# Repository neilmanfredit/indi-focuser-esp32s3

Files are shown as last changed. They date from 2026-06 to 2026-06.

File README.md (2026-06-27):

# indi-focuser-esp32s3


[]()
[]()
[]()
[]()

**A low-cost, open-source motorised telescope focuser for Linux, PHD2, and KStars/Ekos.**

Built around a **28BYJ-48 stepper motor**, **ULN2003 driver board**, and an **Arduino Nano ESP32 (ESP32-S3R8)**. Controlled over USB from any Linux machine via a native INDI driver. No Windows required. No ASCOM required.

3D-printable motor mounts in PETG are included for three telescopes:

| Telescope | Focuser type |
|---|---|
| RVO Horizon 60 ED | Dual-speed rack-and-pinion |
| Celestron NexStar 8SE | SCT mirror-shift |
| SkyWatcher Explorer 200P | 2" Crayford Newtonian |

---

## Why this project exists

Commercial motorised focusers start at £150 and climb quickly. The hardware in this project costs under £15. Most DIY focuser projects target Windows with ASCOM. This one is built for Linux from the ground up — it runs directly on a Raspberry Pi, a mini PC, or any Debian/Arch machine driving your imaging rig.

This project was inspired by the hardware design of [jlecomte/ascom-oag-focuser](https://github.com/jlecomte/ascom-oag-focuser) — an excellent Windows/ASCOM project. The firmware, INDI driver, and 3D files here are independent, original work. See [NOTICE](NOTICE) for full attribution.

---

## What you need to build this

### Electronics (under £15 total)

| Part | Approx cost |
|---|---|
| Arduino Nano ESP32 (ESP32-S3R8) | £8–12 |
| 28BYJ-48 stepper + ULN2003 board (sold as a kit) | £2–3 |
| USB-C cable | Already have one |

### 3D printing

- Any FDM printer
- PETG filament (mandatory for outdoor use — see [docs/3d_printing.md](docs/3d_printing.md))
- ~50g filament per mount

### Tools

- Soldering iron (for heat-set inserts)
- M3 and M2 heat-set inserts
- M3 and M2 socket cap screws (see each SCAD file for exact quantities)
- Calipers (to verify your focuser dimensions before printing)

---

## Repository layout

```
indi-focuser-esp32s3/
│
├── firmware/
│   └── oag_focuser_firmware.ino     Arduino firmware (ESP32-S3)
│
├── indi_driver/
│   ├── indi_oag_focuser.h           INDI driver header
│   ├── indi_oag_focuser.cpp         INDI driver implementation
│   ├── indi_oag_focuser.xml         INDI device descriptor
│   └── CMakeLists.txt               Build system
│
├── 3d_files/
│   ├── rvo-horizon-60ed/
│   │   └── rvo_horizon_60ed_motor_mount.scad
│   ├── celestron-nexstar-8se/
│   │   └── nexstar_8se_motor_mount.scad
│   └── skywatcher-explorer-200p/
│       └── sw_explorer_200p_motor_mount.scad
│
├── scripts/
│   ├── oag_focuser_test.py          Serial test and calibration utility
│   └── 99-oag-focuser.rules         udev stable device symlink
│
├── docs/
│   ├── wiring.md                    Wiring guide
│   ├── build.md                     INDI driver build instructions
│   ├── calibration.md               Focuser calibration procedure
│   └── 3d_printing.md               Print settings and assembly
│
├── LICENSE                          MIT
├── NOTICE                           Third-party attribution
├── CONTRIBUTING.md
└── README.md
```

---

## Wiring

```
Arduino Nano ESP32 (3.3V logic)      ULN2003 board         28BYJ-48 motor
────────────────────────────────     ─────────────          ──────────────
D2  ────────────────────────────►  IN1
D3  ────────────────────────────►  IN2
D4  ────────────────────────────►  IN3
D5  ────────────────────────────►  IN4
5V  ────────────────────────────►  VCC  ◄────────────────── motor +5V
GND ────────────────────────────►  GND
                                    OUT1-4 ─────────────►  motor coils
```

**Key points for the ESP32-S3:**
- The motor runs on **5V** — connect ULN2003 VCC to the board's 5V pin (VBUS), not 3.3V
- The 3.3V GPIO signals are sufficient to trigger the ULN2003 inputs (threshold ~1V)
- Use the **D-label pin names** (D2, D3, D4, D5) in code — bare integers map to raw GPIO numbers on ESP32, which are different from the silkscreen labels
- The board enumerates as `/dev/ttyACM0` on Linux — no CH340 driver needed

See [docs/wiring.md](docs/wiring.md) for the full pinout table and connector details.

---

## Quick start

### Step 1 — Flash the firmware

1. Install the [Arduino IDE](https://www.arduino.cc/en/software)
2. Add the ESP32 board package: **Boards Manager** → search `esp32` → install **Arduino ESP32 Boards** by Arduino
3. Select: **Tools → Board → Arduino ESP32 Boards → Arduino Nano ESP32**
4. Open `firmware/oag_focuser_firmware.ino`
5. Connect via USB-C and click **Upload**

> If the upload fails, double-tap the reset button to enter bootloader mode — the RGB LED will pulse green.

### Step 2 — Test the hardware (no INDI needed)

```bash
pip install pyserial
python3 scripts/oag_focuser_test.py --port /dev/ttyACM0 --test
```

Or interactive mode for manual calibration:

```bash
python3 scripts/oag_focuser_test.py --port /dev/ttyACM0 -i
```

Available commands in interactive mode:

| Command | Action |
|---|---|
| `pos` | Report current position |
| `move <n>` | Move to absolute position n |
| `halt` | Stop immediately |
| `zero` | Set current position as zero |
| `rev on/off` | Reverse motor direction |
| `test` | Run automated self-test |

### Step 3 — Install the udev rule

Gives the device a stable name (`/dev/focuser`) regardless of which USB port you use:

```bash
sudo cp scripts/99-oag-focuser.rules /etc/udev/rules.d/
sudo udevadm control --reload-rules
sudo udevadm trigger
ls -la /dev/focuser   # should appear
```

### Step 4 — Build and install the INDI driver

```bash
# Debian / Ubuntu / Raspberry Pi OS
sudo apt install libindi-dev libnova-dev cmake build-essential

# Arch Linux / Garuda Linux
sudo pacman -S indi libnova cmake base-devel

cd indi_driver
mkdir build && cd build
cmake ..
make -j$(nproc)
sudo make install
```

### Step 5 — Run

```bash
indiserver -v indi_oag_focuser
```

Connect **KStars/Ekos** or **PHD2** to `localhost:7624` and select **OAG Focuser**. Set the serial port to `/dev/ttyACM0` (or `/dev/focuser` if the udev rule is installed).

---

## Serial protocol

The firmware speaks a simple newline-terminated text protocol over USB serial at 115200 baud. Compatible with the protocol used by jlecomte/ascom-oag-focuser, so any tooling built for that project will also work here.

| Command | Response |
|---|---|
| `COMMAND:FOCUSER:HANDSHAKE` | `REPLY:FOCUSER:READY` |
| `COMMAND:FOCUSER:GETPOSITION` | `REPLY:FOCUSER:POSITION:<n>` |
| `COMMAND:FOCUSER:ISMOVING` | `REPLY:FOCUSER:ISMOVING:<0\|1>` |
| `COMMAND:FOCUSER:GETMAXPOSITION` | `REPLY:FOCUSER:MAXPOSITION:32767` |
| `COMMAND:FOCUSER:MOVE:<n>` | `REPLY:FOCUSER:OK` |
| `COMMAND:FOCUSER:HALT` | `REPLY:FOCUSER:OK` |
| `COMMAND:FOCUSER:SETZERO` | `REPLY:FOCUSER:OK` |
| `COMMAND:FOCUSER:GETREVERSE` | `REPLY:FOCUSER:REVERSE:<0\|1>` |
| `COMMAND:FOCUSER:SETREVERSE:<0\|1>` | `REPLY:FOCUSER:OK` |

Position is stored to flash on every stop and survives power cycles.

---

## 3D files

All mounts are **OpenSCAD parametric models**. Open in [OpenSCAD](https://openscad.org/) (free), adjust the parameters at the top to match your focuser, press **F6** to render, then **File → Export → Export as STL**.

**Measure your focuser with calipers before printing.** The key dimension to check per telescope:

| Telescope | File | Key parameter | Default |
|---|---|---|---|
| RVO Horizon 60 ED | `rvo_horizon_60ed_motor_mount.scad` | `focuser_body_w` | 58 mm |
| Celestron NexStar 8SE | `nexstar_8se_motor_mount.scad` | `focus_shaft_od` | 13.1 mm |
| SkyWatcher Explorer 200P | `sw_explorer_200p_motor_mount.scad` | `focuser_body_w` | 76 mm |

Each SCAD file produces all parts needed for that telescope: motor bracket/plate, drive gear, motor pinion, electronics box, and lid.

Print in **PETG**. See [docs/3d_printing.md](docs/3d_printing.md) for full print settings, Bambu Labs H2S notes, and assembly guidance.

---

## Calibration

See [docs/calibration.md](docs/calibration.md) for the full procedure. In summary:

1. Set zero at the mechanical end stop
2. Confirm motor direction (reverse if needed)
3. Measure backlash with a dial indicator
4. Test from INDI

---

## ESP32-S3 firmware notes

Several things behave differently on ESP32-S3 compared to an ATmega Nano. The firmware handles all of these but they are worth understanding:

| Issue | ATmega Nano | ESP32-S3 | Solution in firmware |
|---|---|---|---|
| EEPROM | Built-in hardware | Flash emulation | `EEPROM.begin()` + `EEPROM.commit()` |
| Pin defaults | Defined at startup | Float — no default state | Explicit `pinMode(x, OUTPUT)` for all motor pins |
| Pin numbering | Integer = physical label | Integer = raw GPIO number | D-label names used throughout |
| USB device | `/dev/ttyUSB0` (CH340) | `/dev/ttyACM0` (native CDC) | udev rule provided |
| Logic voltage | 5V | 3.3V | ULN2003 inputs work fine at 3.3V |

---

## Troubleshooting

| Symptom | Likely cause | Fix |
|---|---|-----|
| Motor hums but doesn't turn | ULN2003 VCC on 3.3V pin | Move VCC wire to 5V pin |
| Motor turns wrong way | Wiring or direction flag | `rev on` in test utility |
| `/dev/ttyACM0` missing | Board not in run mode | Double-tap reset; try different cable |
| Handshake fails | Wrong port | `ls /dev/ttyACM*`; check firmware flashed |
| INDI driver not found | XML not installed | Verify `/usr/share/indi/indi_oag_focuser.xml` |
| Position lost on restart | EEPROM not committing | Reflash firmware; do not modify EEPROM calls |
| Gear slips under load | Underpowered 28BYJ-48 | Increase `STEP_DELAY_US` to 1500 in firmware |

---

## Contributing

Pull requests are welcome. Adding a mount design for a new telescope is particularly useful — see [CONTRIBUTING.md](CONTRIBUTING.md).

---

## Licence

MIT — see [LICENSE](LICENSE) — CC BY-NC-SA 4.0, non-commercial use only.

This project is independent and not affiliated with Julien Lecomte's ascom-oag-focuser. See [NOTICE](NOTICE) for attribution.

---

## Acknowledgements

Hardware concept and serial protocol inspired by [jlecomte/ascom-oag-focuser](https://github.com/jlecomte/ascom-oag-focuser) by Julien Lecomte (DarkSkyGeek). Original work in all firmware, driver, and 3D files.

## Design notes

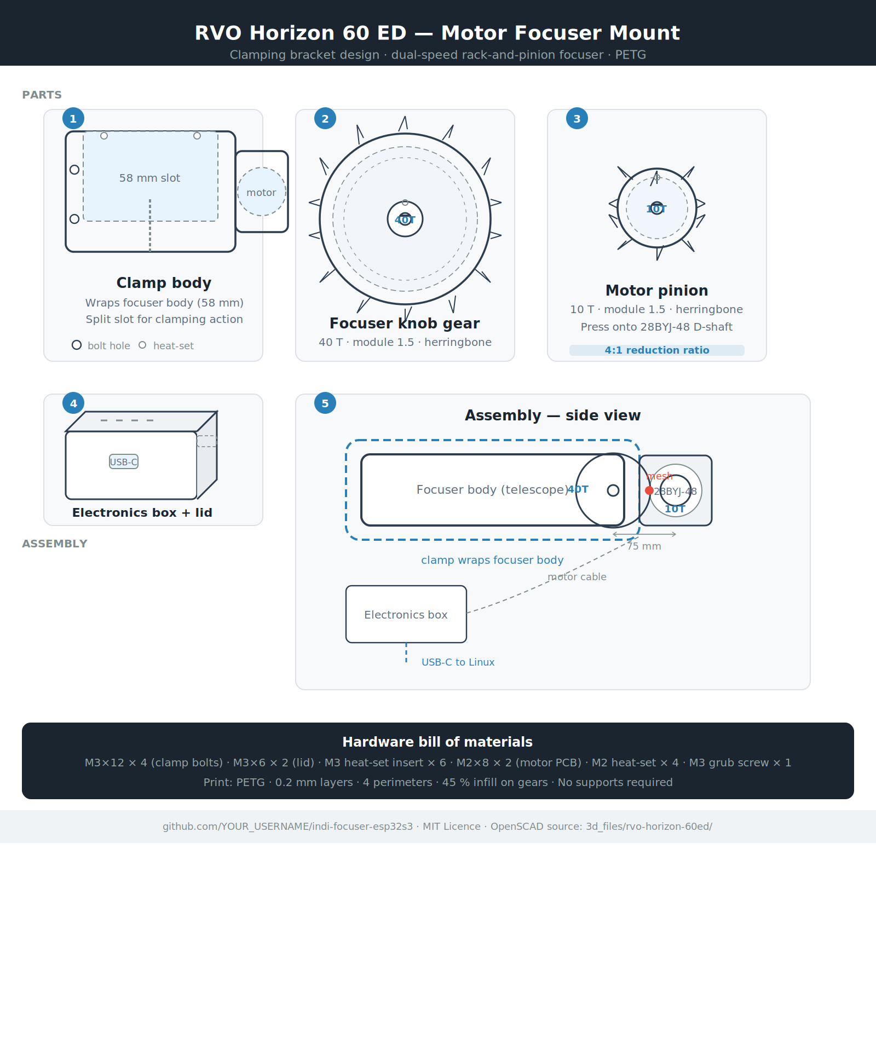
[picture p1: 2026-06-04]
docs/images/rvo_horizon_60ed_mount.png

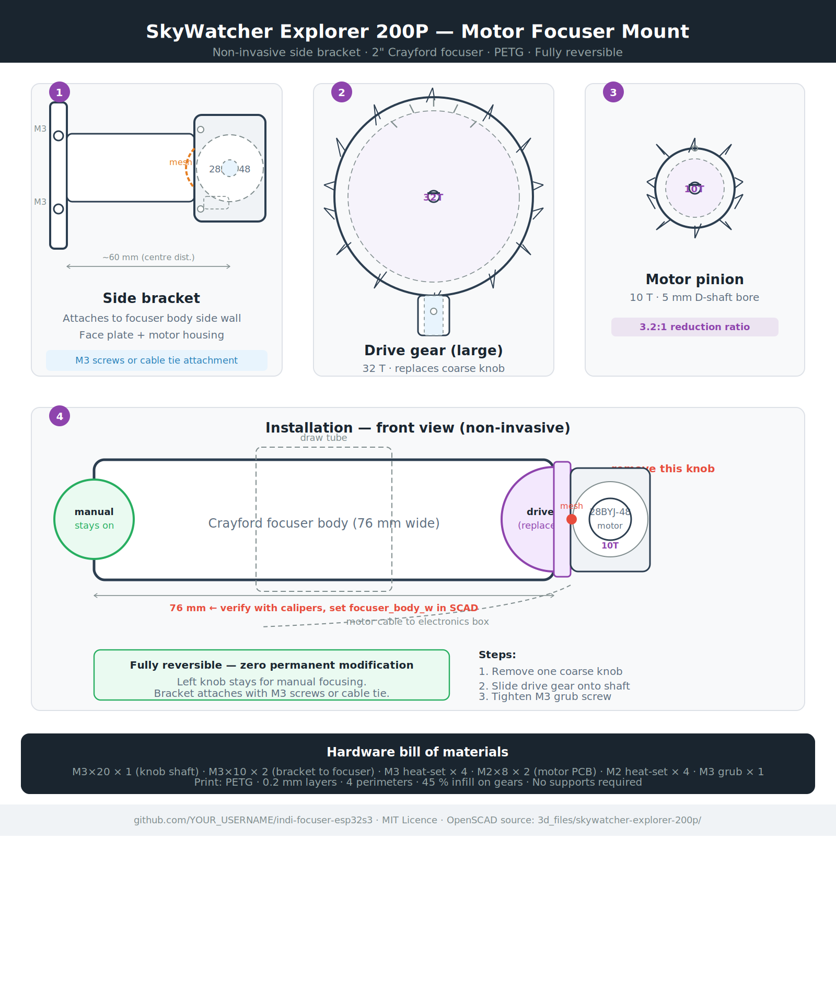
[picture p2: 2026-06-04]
docs/images/sw_explorer_200p_mount.png

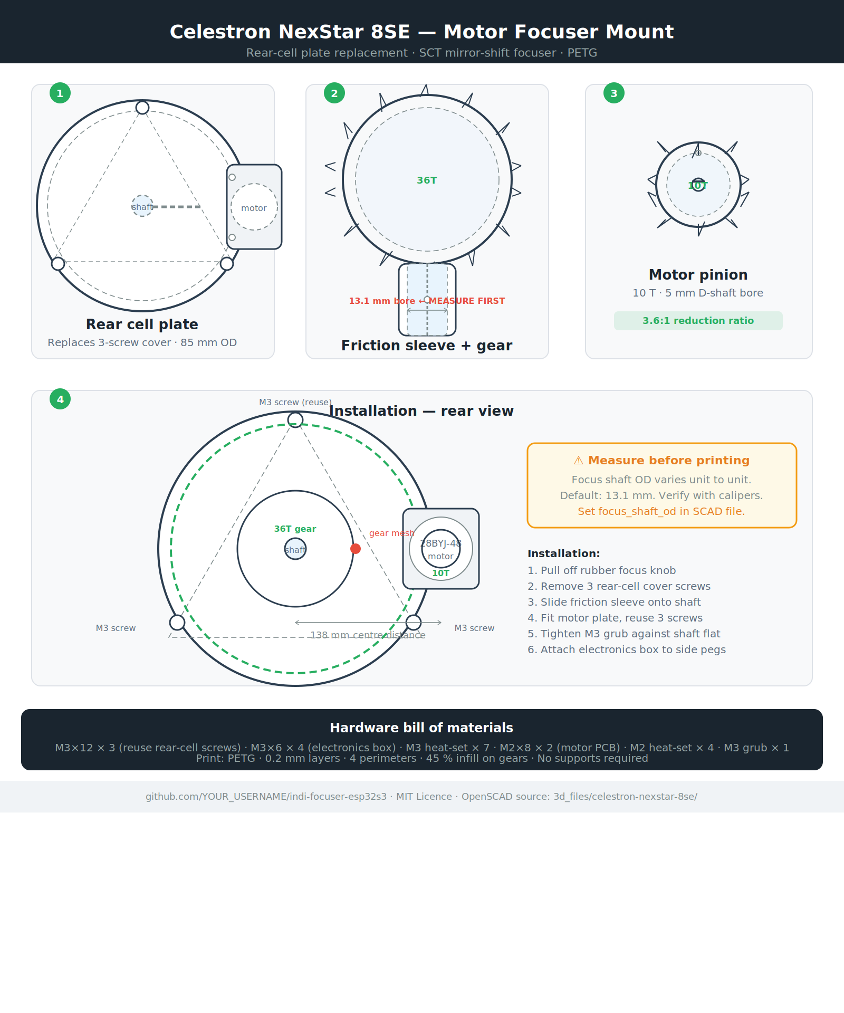
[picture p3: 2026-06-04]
docs/images/nexstar_8se_mount.png

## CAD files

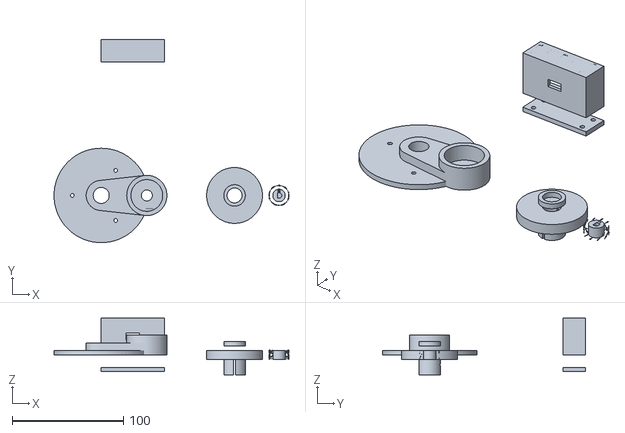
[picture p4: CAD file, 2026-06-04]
3d_files/celestron-nexstar-8se/stl/nexstar_8se_motor_mount.stl
211.5 x 183.0 x 51.0

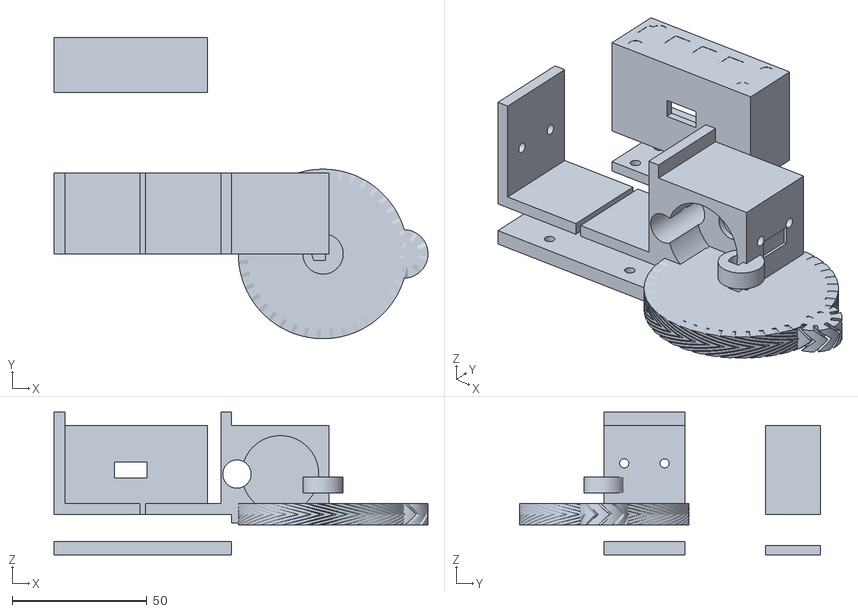
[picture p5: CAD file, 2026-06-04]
3d_files/rvo-horizon-60ed/stl/rvo_horizon_60ed_motor_mount.stl
139.0 x 112.0 x 53.0

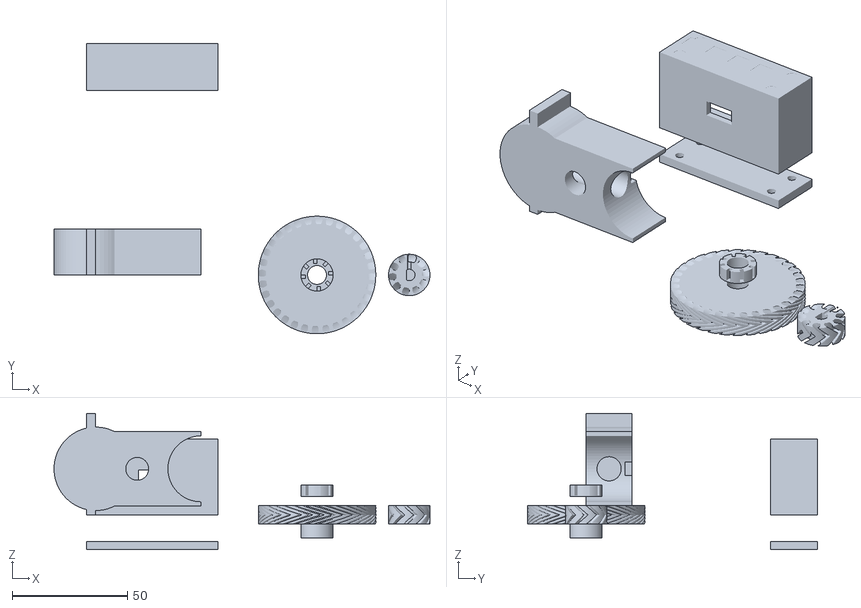
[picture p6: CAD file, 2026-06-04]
3d_files/skywatcher-explorer-200p/stl/sw_explorer_200p_motor_mount.stl
163.1 x 126.0 x 59.0

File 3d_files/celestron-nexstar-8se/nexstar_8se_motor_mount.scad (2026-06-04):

// ============================================================================
// Celestron NexStar 8SE — 28BYJ-48 Motor Focuser Mount
// ============================================================================
//
// Telescope:   Celestron NexStar 8SE (Schmidt-Cassegrain)
// Focuser:     Mirror-shift SCT focuser
//              Focus shaft OD: ~13.1 mm (0.515") — knurled rubber knob pull-off
//              Rear cell: 3-screw cover plate, triangular-pattern back cell
//              Cover plate screws: M3 / #6-32, on a ~52 mm bolt circle
//              Rear cell flange OD: ~100 mm
//
// Motor:       28BYJ-48 (body Ø28 mm, shaft Ø5 mm D-type)
// Design:      Rear-cell plate replacement. The stock 3-screw cover plate is
//              removed. This part replaces it, incorporating:
//              - Motor housing with 28BYJ-48 pocket
//              - Herringbone drive gear for the focus shaft
//              - Motor pinion
//              - Side electronics box for Nano ESP32 + ULN2003
//
// IMPORTANT — SCT mirror focuser shaft note:
//   The focus shaft on the 8SE is the threaded brass tube that the rubber
//   knob sits on. It is ~13 mm OD. Rather than a gear coupling directly on
//   the brass thread (which would damage it), this design uses a friction
//   coupling sleeve that slips over the shaft and is locked with one M3
//   grub screw against the flat on the shaft.
//   MEASURE YOUR SHAFT before printing — some production runs vary ±0.5 mm.
//   Adjust `focus_shaft_od` below.
//
// Print:       PETG, 0.2 mm layers, 4 perimeters, 30% infill
//              Motor plate: flat face down, no supports
//              Gears: flat face down, no supports
//
// Hardware:    M3×12 socket cap (×3) — replaces rear-cell cover screws
//              M3×6  socket cap (×4) — electronics box screws
//              M3 heat-set insert (×7)
//              M2×8  socket cap (×2) — motor mounting
//              M2 heat-set insert (×4)
//              M3 grub/set screw (×1) — friction sleeve clamp
//
// ============================================================================

$fn = 72;

// ── Key dimensions ────────────────────────────────────────────────────────────
// Rear cell geometry
rear_cell_flange_od  = 100.0;  // rear cell flange outer diameter
rear_cell_plate_d    = 85.0;   // cover plate OD (inner shoulder register)
cover_bolt_circle    = 52.0;   // PCD of the 3 cover-plate screws
cover_bolt_d         = 3.4;    // M3 clearance
cover_bolt_count     = 3;      // always 3 on NexStar 8SE
plate_thickness      = 4.0;    // base plate thickness

// Focus shaft geometry
focus_shaft_od       = 13.1;   // shaft OD — VERIFY ON YOUR SCOPE
focus_shaft_sleeve_l = 18;     // length of friction sleeve
focus_shaft_gap      = 0.15;   // clearance on sleeve bore (tight slip fit)

// Motor geometry (28BYJ-48)
motor_body_d         = 28.2;
motor_body_l         = 19.5;
motor_shaft_d        = 5.0;
motor_boss_d         = 9.5;
motor_boss_h         = 1.5;
motor_hole_pitch     = 35;

// Gear
gear_module          = 1.5;
gear_teeth_large     = 36;
gear_teeth_small     = 10;
gear_width           = 8;
herring_angle        = 30;

gear_r_large         = (gear_module * gear_teeth_large) / 2;
gear_r_small         = (gear_module * gear_teeth_small) / 2;
centre_distance      = gear_r_large + gear_r_small;

// Motor plate geometry — motor positioned tangentially to focus shaft axis
// SCT focus shaft is centred in the rear cell (offset from plate centre)
focus_shaft_centre_x =  0;    // shaft is on scope optical axis (plate centre)
focus_shaft_centre_y =  0;

motor_centre_x       = gear_r_large + gear_r_small + focus_shaft_od/2;
motor_centre_y       = 0;

// Electronics box
ebox_w               = 52;
ebox_h               = 28;
ebox_d               = 18;
ebox_wall            = 2.5;
usb_w                = 12;
usb_h                = 6;

// ── Helper modules ─────────────────────────────────────────────────────────────
module m3_heatset(h=6)  { cylinder(d=4.5, h=h); }
module m3_clear(h=20)   { cylinder(d=3.4, h=h); }
module m2_clear(h=10)   { cylinder(d=2.4, h=h); }
module m2_heatset(h=4)  { cylinder(d=3.5, h=h); }

module d_shaft_profile(od, flat_depth, h) {
    // flat_depth = depth of the D-flat from the outer surface
    intersection() {
        cylinder(d=od, h=h);
        translate([-(od/2 - flat_depth), -od/2, 0])
            cube([od, od, h]);
    }
}

// ── Module: herringbone gear 2D profile (spur involute approximation) ─────────
module gear_2d(teeth, mod) {
    pitch_r = (mod * teeth) / 2;
    add_r   = pitch_r + mod;
    ded_r   = pitch_r - 1.25 * mod;
    step    = 360 / teeth;

    difference() {
        circle(r=add_r);
        for (i = [0:teeth-1]) {
            rotate([0, 0, i * step + step/2])
                translate([0, ded_r + (add_r - ded_r)/2, 0])
                    rotate([0, 0, 18])
                        ellipse_approx(
                            (add_r - ded_r) * 0.85,
                            (add_r - ded_r) * 1.1
                        );
        }
    }
    circle(r=ded_r);  // dedendum circle fill
}

module ellipse_approx(rx, ry) {
    scale([rx, ry]) circle(r=1);
}

// ── Module: herringbone gear body ─────────────────────────────────────────────
module hb_gear(teeth, mod, width, helix) {
    half = width / 2;
    for (h = [0, 1]) mirror([0, 0, h])
        linear_extrude(height=half, twist=helix, slices=8, convexity=6)
            gear_2d(teeth, mod);
}

// ── PART 1: Rear-cell motor plate ─────────────────────────────────────────────
module rear_cell_plate() {
    wall_h = plate_thickness + gear_width + 6;  // tall enough for motor housing

    difference() {
        union() {
            // Main circular plate
            cylinder(d=rear_cell_plate_d, h=plate_thickness);

            // Motor housing boss
            translate([motor_centre_x, motor_centre_y, 0])
                cylinder(d=motor_body_d + 8, h=wall_h);

            // Gear bridge (connects shaft centre to motor boss)
            hull() {
                translate([focus_shaft_centre_x, focus_shaft_centre_y, 0])
                    cylinder(d=focus_shaft_od + 14, h=wall_h * 0.6);
                translate([motor_centre_x, motor_centre_y, 0])
                    cylinder(d=motor_body_d + 8, h=wall_h * 0.6);
            }
        }

        // Focus shaft clearance (friction sleeve passes through plate)
        translate([focus_shaft_centre_x, focus_shaft_centre_y, -1])
            cylinder(d=focus_shaft_od + focus_shaft_gap * 2 + 1, h=wall_h + 2);

        // Motor pocket
        translate([motor_centre_x, motor_centre_y, plate_thickness + 2])
            cylinder(d=motor_body_d + 0.4, h=motor_body_l + 2);

        // Motor boss clearance
        translate([motor_centre_x, motor_centre_y, plate_thickness])
            cylinder(d=motor_boss_d + 0.4, h=motor_boss_h + 1);

        // Motor shaft hole
        translate([motor_centre_x, motor_centre_y, -1])
            cylinder(d=motor_boss_d + 1, h=plate_thickness + 2);

        // Cover plate bolt holes (3 screws on PCD)
        for (i = [0:cover_bolt_count-1]) {
            angle = i * (360 / cover_bolt_count) + 60;  // offset to clear motor
            translate([
                cos(angle) * cover_bolt_circle/2,
                sin(angle) * cover_bolt_circle/2,
                -1
            ])
                m3_clear(plate_thickness + 2);
        }

        // Motor mounting holes (M2, on 28BYJ-48 35 mm pitch)
        for (i = [0:1]) {
            rotate([0, 0, i * 180])
            translate([motor_centre_x + motor_hole_pitch/2, motor_centre_y,
                       plate_thickness + motor_body_l + 1.5])
                rotate([180, 0, 0])
                    m2_heatset(4);
        }

        // Electronics box attachment screws (side)
        translate([rear_cell_plate_d/2 - 2, -ebox_w/4, plate_thickness + wall_h/2 - 5])
            rotate([0, 90, 0])
                for (z = [0, ebox_h/2]) {
                    translate([z, 0, 0])
                        m3_heatset(6);
                }
    }
}

// ── PART 2: Friction sleeve (slips over SCT focus shaft) ─────────────────────
// This replaces the rubber focus knob. The large herringbone gear is integrated
// onto this sleeve. The motor drives the gear; the sleeve turns the focus shaft.
module friction_sleeve_with_gear() {
    sleeve_od = focus_shaft_od + focus_shaft_gap * 2 + 6;  // outer of sleeve

    difference() {
        union() {
            // Gear portion
            hb_gear(gear_teeth_large, gear_module, gear_width, herring_angle);

            // Sleeve hub (below gear)
            translate([0, 0, -focus_shaft_sleeve_l])
                cylinder(d=sleeve_od, h=focus_shaft_sleeve_l);

            // Top cap
            translate([0, 0, gear_width])
                cylinder(d=sleeve_od, h=4);
        }
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

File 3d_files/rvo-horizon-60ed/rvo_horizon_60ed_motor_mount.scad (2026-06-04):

// ============================================================================
// RVO Horizon 60 ED — 28BYJ-48 Motor Focuser Mount
// ============================================================================
//
// Telescopes:  RVO Horizon 60 ED Doublet Refractor
// Focuser:     Dual-speed rack-and-pinion, 2" draw tube
//              Coarse knob shaft: ~8 mm round with flat (D-shaft)
//              Fine knob (10:1) shaft: ~6 mm
//              Focuser body outer width: ~58 mm
//
// Motor:       28BYJ-48 stepper (body Ø28 mm, shaft Ø5 mm)
// Driver PCB:  ULN2003 board (fits in electronics box below)
// MCU:         Arduino Nano ESP32 (Nano form factor)
//
// Design:      Clamp around focuser body. Motor sits beside coarse knob
//              axis, drives via herringbone gear + pinion on the knob shaft.
//              Electronics box clips onto the side of the clamp body.
//
// Print:       PETG, 0.2 mm layers, 4 perimeters, 30% infill minimum
//              Orientation: clamp flat side down (no supports needed)
//
// Parts:       Motor clamp body (×1)
//              Lid (×1)
//              Focuser knob gear (large, ×1) — replaces the coarse knob
//              Motor pinion (small, ×1)
//              Electronics box (×1)
//              Electronics lid (×1)
//
// Hardware:    M3×12 socket cap (×4) — clamp bolts
//              M3×6  socket cap (×2) — lid screws
//              M3 heat-set insert (×6)
//              M2×8  socket cap (×2) — motor mounting
//              M2 heat-set insert (×4)
//
// ============================================================================

$fn = 64;

// ── Key dimensions ────────────────────────────────────────────────────────────
focuser_body_w     = 58;   // focuser body outer width (mm)
focuser_body_h     = 30;   // focuser body outer height (mm)
focuser_shaft_d    = 8.2;  // coarse knob shaft diameter (clearance fit)
clamp_wall         = 4;    // wall thickness of clamp
clamp_length       = 30;   // clamp depth (along optical axis)

// Motor geometry (28BYJ-48)
motor_body_d       = 28.2;  // motor body OD (clearance)
motor_body_l       = 19.5;  // motor body length (excl. shaft boss)
motor_shaft_d      = 5.0;   // motor shaft diameter
motor_shaft_flat   = 3.0;   // chord of D-flat on motor shaft
motor_mount_hole_d = 2.2;   // M2 clearance for motor PCB holes
motor_boss_d       = 9.5;   // motor front boss diameter
motor_boss_h       = 1.5;   // motor front boss height
motor_hole_pitch   = 35;    // motor mounting hole pitch (28BYJ-48 standard)

// Gear dimensions (herringbone, matching jlecomte approach)
gear_module        = 1.5;   // module — coarser for strength in PETG
gear_teeth_large   = 40;    // focuser knob gear (large)
gear_teeth_small   = 10;    // motor pinion (small)
gear_width         = 8;     // gear face width
herring_angle      = 30;    // herringbone helix angle (degrees)

// Derived gear radii
gear_r_large       = (gear_module * gear_teeth_large) / 2;
gear_r_small       = (gear_module * gear_teeth_small) / 2;
centre_distance    = gear_r_large + gear_r_small;

// Electronics box (fits Arduino Nano ESP32 + ULN2003 board)
ebox_w             = 52;   // box inner width
ebox_h             = 28;   // box inner height
ebox_d             = 18;   // box inner depth
ebox_wall          = 2.5;
usb_cutout_w       = 12;   // USB-C cutout
usb_cutout_h       = 6;

// ── Module: D-shaft profile ───────────────────────────────────────────────────
module d_shaft(d, flat_chord, h) {
    flat_offset = d/2 - (d/2 - sqrt((d/2)^2 - (flat_chord/2)^2));
    intersection() {
        cylinder(d=d, h=h);
        translate([-d, -flat_chord/2, 0])
            cube([d + d/2 - flat_offset, flat_chord, h]);
    }
}

// ── Module: herringbone gear tooth profile (approximate involute) ─────────────
module herringbone_gear(teeth, mod, width, helix_deg, bore_d, bore_type="round") {
    pitch_r = (mod * teeth) / 2;
    addendum = mod;
    dedendum = 1.25 * mod;
    tooth_h  = addendum + dedendum;
    half_w   = width / 2;

    difference() {
        union() {
            // Approximate herringbone via two mirrored twisted extrusions
            for (half = [0, 1]) {
                mirror([0, 0, half])
                linear_extrude(height=half_w, twist=helix_deg, slices=8, convexity=4)
                    gear_2d_profile(teeth, mod);
            }
        }
        // Bore
        if (bore_type == "d_shaft") {
            translate([0, 0, -0.1])
                d_shaft(bore_d, bore_d * 0.6, width + 0.2);
        } else {
            translate([0, 0, -0.1])
                cylinder(d=bore_d + 0.2, h=width + 0.2);
        }
    }
}

// 2D gear profile (simplified involute approximation)
module gear_2d_profile(teeth, mod) {
    pitch_r  = (mod * teeth) / 2;
    add_r    = pitch_r + mod;
    ded_r    = pitch_r - 1.25 * mod;
    tooth_w  = PI * mod / 2;  // approximate tooth width at pitch circle

    difference() {
        circle(r=add_r);
        for (i = [0:teeth-1]) {
            rotate([0, 0, i * (360/teeth)])
                translate([0, ded_r, 0])
                    rotate([0, 0, 0])
                        square([tooth_w * 0.6, (add_r - ded_r) * 2.2], center=true);
        }
    }
    circle(r=ded_r);
}

// ── Module: motor pocket ──────────────────────────────────────────────────────
module motor_pocket() {
    union() {
        cylinder(d=motor_body_d + 0.4, h=motor_body_l);
        // shaft clearance
        translate([0, 0, -2])
            cylinder(d=motor_boss_d + 0.4, h=motor_boss_h + 2.2);
    }
}

// ── Module: M3 heat-set pocket ────────────────────────────────────────────────
module m3_heatset(h=6) {
    cylinder(d=4.5, h=h);  // 4.5 mm for M3 insert
}

// ── Module: M3 bolt clearance ─────────────────────────────────────────────────
module m3_clear(h=20) {
    cylinder(d=3.4, h=h);
}

// ── PART 1: Clamp body ────────────────────────────────────────────────────────
module clamp_body() {
    fw = focuser_body_w + clamp_wall * 2;
    fh = focuser_body_h + clamp_wall * 2;

    motor_offset_x = focuser_body_w/2 + clamp_wall + centre_distance;
    motor_offset_z = focuser_body_h/2; // centre of focuser shaft

    difference() {
        union() {
            // Main clamp block
            cube([fw, clamp_length, fh]);

            // Motor housing extension
            translate([fw, 0, motor_offset_z - motor_body_d/2 - clamp_wall])
                cube([motor_body_d + clamp_wall * 2, clamp_length, motor_body_d + clamp_wall * 2]);
        }

        // Focuser slot (open bottom for clamping)
        translate([clamp_wall, -1, clamp_wall])
            cube([focuser_body_w, clamp_length + 2, focuser_body_h + 5]);

        // Motor pocket in housing extension
        translate([fw + clamp_wall + motor_body_d/2, clamp_length/2, motor_offset_z]) {
            rotate([90, 0, 0])
                motor_pocket();
        }

        // Motor shaft hole through to gear space
        translate([fw + clamp_wall/2, clamp_length/2, motor_offset_z])
            rotate([90, 0, 0])
                cylinder(d=motor_boss_d + 1, h=clamp_length + 2, center=true);

        // Clamp split slot (bottom)
        translate([fw/2 - 1, -1, -1])
            cube([2, clamp_length + 2, clamp_wall + 2]);

        // M3 clamp bolt holes (side)
        for (pos = [clamp_length * 0.25, clamp_length * 0.75]) {
            translate([-1, pos, fh/2])
                rotate([0, 90, 0])
                    m3_clear(fw + motor_body_d + clamp_wall * 3 + 2);
        }

        // M3 heat-set pockets for lid
        for (pos = [clamp_length * 0.2, clamp_length * 0.8]) {
            translate([fw/4, pos, fh - 0.1])
                m3_heatset(6);
            translate([3*fw/4, pos, fh - 0.1])
                m3_heatset(6);
        }

        // USB cable routing notch (side)
        translate([fw + motor_body_d + clamp_wall * 2 - 1,
                   clamp_length/2 - usb_cutout_w/2,
                   motor_offset_z - usb_cutout_h/2])
            cube([4, usb_cutout_w, usb_cutout_h]);
    }
}

// ── PART 2: Clamp lid ─────────────────────────────────────────────────────────
module clamp_lid() {
    fw = focuser_body_w + clamp_wall * 2;
    fh = focuser_body_h + clamp_wall * 2;

    difference() {
        cube([fw, clamp_length, clamp_wall + 1]);

        // M3 lid bolt clearance (matching heat-sets in body)
        for (pos = [clamp_length * 0.2, clamp_length * 0.8]) {
            translate([fw/4, pos, -0.1])
                m3_clear(clamp_wall + 2);
            translate([3*fw/4, pos, -0.1])
                m3_clear(clamp_wall + 2);
        }
    }
}
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

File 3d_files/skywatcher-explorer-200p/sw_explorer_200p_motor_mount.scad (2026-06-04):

// ============================================================================
// SkyWatcher Explorer 200P — 28BYJ-48 Motor Focuser Mount
// ============================================================================
//
// Telescope:   SkyWatcher Explorer 200P (200mm f/6 Newtonian reflector)
// Focuser:     Single-speed Crayford (rack-and-pinion on some units)
//              The 200P ships with a 2" single-speed Crayford focuser.
//              Focuser body outer width: ~76 mm
//              Coarse knob shaft: ~8 mm round, M4 grub-screw secured
//              Focuser body depth (front-to-back, optical axis): ~34 mm
//              Standard Skywatcher Crayford focuser knob rubber OD: ~25.5 mm
//
// Motor:       28BYJ-48 (body Ø28 mm, 5V, shaft Ø5 mm D-type)
// Design:      Non-invasive bracket. One of the two coarse focus knobs is
//              removed. The bracket replaces it on the focuser shaft.
//              The motor sits beside the bracket and drives a gear glued to
//              the focuser knob shaft.
//
//              This is the simplest, most reversible design — no glue, no
//              permanent modification to the focuser.
//
// Print:       PETG, 0.2 mm layers, 4 perimeters, 25%+ infill
//              Motor bracket: flat mounting face down, no supports needed
//              Gears: flat down, no supports
//
// Hardware:    M3×20 socket cap (×1) — replaces focuser knob retaining screw
//              M3×10 socket cap (×2) — bracket to focuser body
//              M3 heat-set insert (×4)
//              M2×8  socket cap (×2) — motor PCB mounting
//              M2 heat-set insert (×4)
//              M3 grub screw ×1 — drive gear clamp
//
// ============================================================================

$fn = 64;

// ── Focuser body dimensions ────────────────────────────────────────────────────
focuser_body_w     = 76;    // outer width of Crayford focuser body
focuser_body_h     = 40;    // outer height (top to bottom of body)
focuser_body_d     = 34;    // depth (front to back, along optical axis)
focuser_shaft_d    = 8.2;   // focuser knob shaft OD (clearance)
knob_rubber_od     = 25.5;  // original rubber knob OD

// Wall and clamp
clamp_wall         = 4.0;
clamp_depth        = 20;    // how much of the focuser body the clamp grips

// Motor geometry (28BYJ-48)
motor_body_d       = 28.2;
motor_body_l       = 19.5;
motor_shaft_d      = 5.0;
motor_boss_d       = 9.5;
motor_boss_h       = 1.5;
motor_hole_pitch   = 35;    // 28BYJ-48 mounting hole PCD

// Gear dimensions
gear_module        = 1.5;
gear_teeth_drive   = 32;    // gear on focuser knob shaft
gear_teeth_pinion  = 10;    // gear on motor shaft
gear_width         = 8;
herring_angle      = 30;

gear_r_drive       = (gear_module * gear_teeth_drive) / 2;
gear_r_pinion      = (gear_module * gear_teeth_pinion) / 2;
centre_dist        = gear_r_drive + gear_r_pinion;

// Electronics box
ebox_w             = 52;
ebox_h             = 28;
ebox_d             = 18;
ebox_wall          = 2.5;
usb_w              = 12;
usb_h              = 6;

// ── Helper modules ─────────────────────────────────────────────────────────────
module m3_heatset(h=6)  { cylinder(d=4.5, h=h); }
module m3_clear(h=20)   { cylinder(d=3.4, h=h); }
module m2_clear(h=10)   { cylinder(d=2.4, h=h); }
module m2_heatset(h=4)  { cylinder(d=3.5, h=h); }

module d_shaft_profile(od, flat_depth, h) {
    intersection() {
        cylinder(d=od, h=h);
        translate([-(od/2 - flat_depth), -od/2, 0])
            cube([od, od, h]);
    }
}

// ── 2D involute gear approximation ────────────────────────────────────────────
module gear_2d(teeth, mod) {
    pitch_r = (mod * teeth) / 2;
    add_r   = pitch_r + mod;
    ded_r   = pitch_r - 1.25 * mod;
    step    = 360 / teeth;

    difference() {
        circle(r=add_r);
        for (i = [0:teeth-1]) {
            rotate([0, 0, i * step + step/2])
                translate([0, ded_r + (add_r - ded_r)/2])
                    scale([(add_r-ded_r)*0.45, (add_r-ded_r)*0.6])
                        circle(r=1);
        }
    }
    circle(r=ded_r);
}

// ── Herringbone gear body ─────────────────────────────────────────────────────
module hb_gear(teeth, mod, width, helix) {
    half = width/2;
    for (h = [0,1]) mirror([0,0,h])
        linear_extrude(height=half, twist=helix, slices=8, convexity=6)
            gear_2d(teeth, mod);
}

// ── PART 1: Side-bracket motor mount ─────────────────────────────────────────
// This mounts to the side of the focuser body (where one knob was removed).
// It positions the motor so the gears mesh at the correct centre distance.
module motor_bracket() {
    // Bracket body dimensions
    bw = motor_body_d + clamp_wall * 2 + 10;  // bracket width
    bh = focuser_body_h + clamp_wall;           // bracket height
    bd = clamp_depth;                            // bracket depth (grip on focuser)

    // Motor is positioned so its shaft is at centre_dist from focuser shaft
    // Focuser shaft is at [focuser_body_w/2, 0] (left face of focuser)
    // The bracket attaches to the left face, so in our local coords
    // focuser shaft is at x=0 and motor shaft is at x=centre_dist
    motor_x = centre_dist;
    motor_z = focuser_body_h / 2;  // vertically centred on focuser

    difference() {
        union() {
            // Flat face plate (mounts to focuser side)
            cube([clamp_wall, bd, bh]);

            // Motor housing
            translate([clamp_wall, bd/2, motor_z])
                rotate([90, 0, 0])
                    cylinder(d=motor_body_d + 8, h=bd + 0.001, center=true);

            // Structural web between face plate and motor housing
            translate([0, 0, motor_z - motor_body_d/2 - clamp_wall/2])
                cube([motor_x + motor_body_d/2 + clamp_wall, bd, motor_body_d + clamp_wall]);
        }

        // Motor pocket (from the right side)
        translate([motor_x + motor_body_d/2 + clamp_wall, bd/2, motor_z])
            rotate([90, 0, 0])
                cylinder(d=motor_body_d + 0.4, h=motor_body_l + 2, center=true);
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

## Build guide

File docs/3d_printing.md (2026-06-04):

# 3D Printing Guide

## Why PETG

All mounts are designed for **PETG**. Do not use PLA for any part that will be left attached to a telescope outdoors.

| Property | PLA | PETG |
|---|-----|---|
| Heat resistance | ~60°C — warps in summer sun on a dark OTA | ~80°C |
| Cold brittleness | Brittle below ~5°C | Flexible to −20°C |
| UV resistance | Degrades in 6–12 months outdoors | Adequate |
| Layer adhesion | Good | Excellent — critical for gear teeth |
| Moisture | Weakens over time | Largely resistant |

ASA is preferable if you have it dialled in on your printer. ABS is not recommended — poor layer adhesion and warping risk.

## Print settings

| Parameter | Value |
|---|---|
| Layer height | 0.2 mm |
| Perimeters / walls | 4 |
| Top/bottom layers | 5 |
| Infill | 30% structural parts; 45% gears |
| Infill pattern | Gyroid or grid |
| Nozzle temp | 235–245°C (PETG) |
| Bed temp | 70–80°C |
| Bed surface | Textured PEI |
| Fan cooling | 30–50% (reducing cooling improves PETG layer bonding) |
| First layer speed | 20 mm/s |
| Wall speed | 25–30 mm/s for gears; 40–50 mm/s elsewhere |
| Supports | None — all parts are support-free in stated orientation |

**Dry your filament before printing gears.** Wet PETG strings between teeth and produces weak, rough gear faces. Dry at 65°C for 4–6 hours in a filament dryer or oven.

## Bambu Labs H2S specific

- AMS: PETG in slot 1, single-material print
- Plate: textured PEI
- Seam: rear (hidden on gear face)
- Enable "Slow down for overhangs" — helps gear tooth tops
- Wall generator: Classic mode for gears (more predictable seam placement)

## Part orientations

### Clamp / bracket bodies
Flat mounting face down. The internal focuser slot faces down and acts as its own bridge.

### Gears
Flat face down. No supports needed. The herringbone tooth profile prints cleanly because each layer is fully supported by the previous one.

### Electronics boxes
Open top facing up. No supports.

## Heat-set inserts

All bolt holes use knurled M3 or M2 heat-set inserts.

1. Heat your soldering iron to 180–200°C.
2. Use a pointed brass tip (dedicated insert tip is ideal).
3. Place the insert on the hole and press gently and perpendicularly.
4. Stop when the insert is flush with or 0.2 mm below the surface.
5. Let cool fully (60 seconds minimum) before applying any load.

Do not use a flat iron tip — it pushes material sideways and produces a weak, crooked insert.

## Post-print checks

After printing gears:
1. Test-mesh the large and small gear by hand before installing the motor.
2. The mesh should be smooth with a small, consistent gap — not tight, not sloppy.
3. If tight: increase `centre_dist` in the SCAD file by 0.1 mm and reprint the bracket.
4. If loose/rattly: decrease by 0.1 mm.

After printing the clamp or bracket:
1. Test-fit on the focuser before inserting heat-sets.
2. The clamping slot or bracket face should contact the focuser body without forcing.
3. If tight: light filing or sanding on the contact face. Do not reprint — PETG can be eased much faster than reprinting.

## Electronics box assembly

The Nano ESP32 fits the standard Arduino Nano form factor.
The ULN2003 board sits beside it in the box.
Route the motor cable out through the rear slot; the USB-C cable exits through the front cutout.

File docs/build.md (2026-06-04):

# Building the INDI Driver

## Dependencies

### Debian / Ubuntu / Raspberry Pi OS

```bash
sudo apt update
sudo apt install libindi-dev libnova-dev cmake build-essential
```

### Arch Linux / Garuda Linux

```bash
sudo pacman -S indi libnova cmake base-devel
```

### Fedora / RHEL

```bash
sudo dnf install libindi-devel libnova-devel cmake gcc-c++
```

## Build

```bash
cd indi_driver
mkdir build && cd build
cmake ..
make -j$(nproc)
```

## Install

```bash
sudo make install
```

This installs:
- `/usr/local/bin/indi_oag_focuser` — the driver binary
- `/usr/share/indi/indi_oag_focuser.xml` — the device descriptor (tells INDI clients this driver exists)

## Run

```bash
indiserver -v indi_oag_focuser
```

Default serial port is `/dev/ttyACM0`. Change it in the INDI client connection settings, or install the udev rule to get a stable `/dev/oag_focuser` symlink.

## Using with KStars / Ekos

1. Start `indiserver` as above.
2. In KStars: Tools → Ekos → New Profile.
3. Add **Focuser → OAG Focuser** to the profile.
4. Connect, set port to `/dev/ttyACM0`.

## Using with PHD2

PHD2 does not drive the focuser directly. Connect via Ekos or use a separate INDI client. PHD2 monitors the guide star while the imaging application commands focus changes.

## Troubleshooting

| Problem | Fix |
|---|-----|
| `indi_oag_focuser: command not found` | Run `sudo make install` again; check `/usr/local/bin` is on your PATH |
| Driver not listed in INDI client | Check `/usr/share/indi/indi_oag_focuser.xml` exists |
| `No response to handshake` | Check port name; confirm firmware flashed; try `python3 scripts/oag_focuser_test.py` first |
| Build fails: `libindi not found` | Install `libindi-dev` (Debian) or `indi` (Arch) |

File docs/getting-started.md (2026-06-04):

# Getting Started

This guide takes you from unboxed parts to a working motorised focuser connected to PHD2 or KStars/Ekos. Follow the steps in order.

---

## What you need

- Arduino Nano ESP32 (ESP32-S3R8)
- 28BYJ-48 stepper motor + ULN2003 driver board (sold as a kit, ~£3)
- USB-C cable
- Linux machine (desktop, laptop, or Raspberry Pi)
- 3D printed motor mount for your telescope (see [3d_files/](../3d_files/))

---

## 1. Wire the hardware

Connect the ULN2003 board to the Nano ESP32:

| ULN2003 pin | Nano ESP32 pin |
|---|---|
| IN1 | D2 |
| IN2 | D3 |
| IN3 | D4 |
| IN4 | D5 |
| VCC | **5V** (not 3.3V) |
| GND | GND |

Plug the 28BYJ-48 motor directly into the ULN2003 board's 5-pin socket.

**Do not power the motor from the 3.3V pin.** The motor needs 5V. The GPIO signals at 3.3V are fine — the ULN2003 input threshold is about 1V.

---

## 2. Flash the firmware

1. Download and install the [Arduino IDE](https://www.arduino.cc/en/software)
2. Open **Boards Manager**, search `esp32`, install **Arduino ESP32 Boards** by Arduino
3. Set board to **Arduino ESP32 Boards → Arduino Nano ESP32**
4. Open `firmware/oag_focuser_firmware.ino`
5. Connect the Nano ESP32 via USB-C
6. Click **Upload**

If the upload fails: double-tap the reset button until the RGB LED pulses green, then try again.

---

## 3. Verify it works

```bash
pip install pyserial
python3 scripts/oag_focuser_test.py --port /dev/ttyACM0 --test
```

You should see the motor turn and return, with a `PASS` result. If it hums but doesn't turn, check the 5V wiring.

---

## 4. Install the stable device symlink

```bash
sudo cp scripts/99-oag-focuser.rules /etc/udev/rules.d/
sudo udevadm control --reload-rules && sudo udevadm trigger
ls -la /dev/focuser
```

From this point you can use `/dev/focuser` instead of `/dev/ttyACM0`.

---

## 5. Install the INDI driver

```bash
# Debian / Ubuntu / Raspberry Pi OS
sudo apt install libindi-dev libnova-dev cmake build-essential

# Arch / Garuda
sudo pacman -S indi libnova cmake base-devel

cd indi_driver
mkdir build && cd build
cmake .. && make -j$(nproc) && sudo make install
```

---

## 6. Calibrate the focuser

```bash
python3 scripts/oag_focuser_test.py --port /dev/focuser -i
```

1. Manually rotate your focuser to its physical inward end stop
2. Type `zero` to set that as position 0
3. Type `move 500` and watch the focuser move — if it goes the wrong way, type `rev on` and re-zero
4. Type `quit`

See [calibration.md](calibration.md) for backlash measurement.

---

## 7. Connect to KStars/Ekos or PHD2

Start the INDI server:

```bash
indiserver -v indi_oag_focuser
```

**KStars/Ekos:**
1. Tools → Ekos → New Profile (or edit existing)
2. Add Focuser → OAG Focuser
3. Connect, set port to `/dev/focuser`

**PHD2:**
PHD2 does not command the focuser directly. Use Ekos as the primary imaging application; PHD2 guides while Ekos handles focus.

---

## Done

Your focuser should now respond to commands from your imaging software. If anything doesn't work, check the [Troubleshooting](../README.md#troubleshooting) section in the main README or open an issue.

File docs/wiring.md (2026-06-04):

# Wiring Guide — Arduino Nano ESP32 + ULN2003 + 28BYJ-48

## Overview

The ESP32-S3 runs at 3.3 V. The 28BYJ-48 motor needs 5 V. The ULN2003 driver board sits between them and handles the voltage difference.

```
Arduino Nano ESP32          ULN2003 board         28BYJ-48 motor
─────────────────           ─────────────          ──────────────
D2  ──────────────────────► IN1
D3  ──────────────────────► IN2
D4  ──────────────────────► IN3
D5  ──────────────────────► IN4
5V  ──────────────────────► VCC                ◄── motor red wire
GND ──────────────────────► GND
                             OUT1-4 ──────────────► motor coil wires
```

## Pin mapping detail

| Nano ESP32 label | ESP32-S3 GPIO | Function |
|---|---|---|
| D2 | GPIO5 | Stepper IN1 |
| D3 | GPIO6 | Stepper IN2 |
| D4 | GPIO7 | Stepper IN3 |
| D5 | GPIO8 | Stepper IN4 |
| 5V | VBUS | Motor + ULN2003 power |
| GND | GND | Common ground |

**Always use the D-label names (D2, D3, D4, D5) in code, not raw GPIO numbers.** On the Nano ESP32, bare integers map to raw GPIO numbers which are different from the silkscreen labels.

## Power

- ULN2003 VCC must be 5 V. Connect to the board's **5V pin** (available when USB is connected).
- Do not connect ULN2003 VCC to the 3.3 V pin — the motor will not turn properly.
- The GPIO signals (3.3 V) are sufficient to trigger the ULN2003 inputs, which have a ~1 V threshold.

## Important ESP32-S3 differences from ATmega Nano

1. **Logic level is 3.3 V** — do not connect 5 V signals to GPIO pins.
2. **`pinMode(x, OUTPUT)` is mandatory** — pins do not default to a safe state.
3. **EEPROM requires `begin()` and `commit()`** — the firmware handles both.
4. **USB port is `/dev/ttyACM0`** not `/dev/ttyUSB0` — no CH340 chip on this board.

## 28BYJ-48 motor connector

The motor has a 5-pin JST connector. Pin order (left to right, looking at the socket):

| Pin | Colour | Function |
|-----|---|---|
| 1 | Orange | Coil A1 |
| 2 | Yellow | Coil A2 |
| 3 | Pink | Coil B1 |
| 4 | Blue | Coil B2 |
| 5 | Red | +5V common |

The ULN2003 board has a matching socket — just plug the motor directly in.

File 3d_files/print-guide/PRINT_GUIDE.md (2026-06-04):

# Bambu Studio Print Guide

Complete slicing instructions for all motor mount parts.
Printer: Bambu Lab H2S (also works on X1C, P1S, A1).
Filament: PETG — mandatory for outdoor use.

---

## Before you start

### 1. Export STL files from OpenSCAD

The files in `3d_files/` are `.scad` source files. You need to export STL before slicing.

1. Install [OpenSCAD](https://openscad.org/downloads.html) (free)
2. Open your telescope's `.scad` file
3. To export parts individually, comment out all parts except the one you want:

```openscad
// Example — export only the drive gear:
drive_gear();

// Comment out everything else:
// motor_bracket();
// motor_pinion();
// electronics_box();
// electronics_lid();
```

4. Press **F6** to render (10–30 seconds for gears)
5. **File → Export → Export as STL**
6. Repeat for each part

### 2. Dry your filament

PETG must be dry before printing gears. Wet filament strings between teeth and produces weak, rough tooth surfaces.

Dry at **65°C for 4–6 hours** in a filament dryer or low-temperature oven before printing any gear parts.

### 3. Import presets (optional)

Three JSON preset files are included in `print-guide/process-presets/`:

| File | Use for |
|---|---|
| `indi-focuser-PETG-filament.json` | Filament settings |
| `indi-focuser-PETG-structural.json` | Clamp body, brackets, electronics box |
| `indi-focuser-PETG-gears.json` | All gears and the friction sleeve |

To import in Bambu Studio:
**Settings → Filament / Process → Import** → select the JSON file.

If you prefer to set manually, all values are listed in the tables below.

---

## Slicer settings

### Filament (PETG)

| Parameter | Value |
|---|---|
| Nozzle temp | 240°C |
| Bed temp | 70°C |
| Plate type | Textured PEI (not smooth — PETG sticks too aggressively) |
| Fan speed | 40–60% |
| Retraction | 0.8 mm at 35 mm/s |

### Structural parts

Applies to: clamp body, clamp lid, side bracket, electronics box, electronics lid, rear cell plate, friction sleeve hub.

| Parameter | Value |
|---|---|
| Layer height | 0.20 mm |
| First layer height | 0.20 mm |
| Wall loops | 4 |
| Top/bottom layers | 5 |
| Infill density | 30% |
| Infill pattern | Gyroid |
| Outer wall speed | 60 mm/s |
| Inner wall speed | 80 mm/s |
| Infill speed | 150 mm/s |
| First layer speed | 30 mm/s |
| Support | **None** |
| Seam position | Rear |
| Brim | None |

### Gears

Applies to: focuser knob gear, motor pinion, drive gear.

| Parameter | Value |
|---|---|
| Layer height | 0.20 mm |
| First layer height | 0.20 mm |
| Wall loops | 4 |
| Top/bottom layers | 5 |
| Infill density | **45%** |
| Infill pattern | Gyroid |
| Outer wall speed | **40 mm/s** — slower for tooth accuracy |
| Inner wall speed | 60 mm/s |
| Infill speed | 120 mm/s |
| First layer speed | 25 mm/s |
| Support | **None** |
| Seam position | Rear |
| Brim | None |

---

## Part orientations

Correct orientation is critical — wrong orientation produces weak layer lines across stress points.

### RVO Horizon 60 ED

| Part | Orientation | Notes |
|---|---|---|
| Clamp body | Flat back face on bed | Focuser slot opening faces up |
| Clamp lid | Flat outer face on bed | |
| Focuser knob gear | Flat face (non-herringbone side) on bed | |
| Motor pinion | Flat face on bed | |
| Electronics box | Open top facing up | |
| Electronics lid | Flat outer face on bed | |

### Celestron NexStar 8SE

| Part | Orientation | Notes |
|---|---|---|
| Rear cell plate | Flat back face on bed | Motor housing boss faces up |
| Friction sleeve + gear | Gear face flat on bed | Sleeve hub points up |
| Motor pinion | Flat face on bed | |
| Electronics box | Open top facing up | |
| Electronics lid | Flat outer face on bed | |

### SkyWatcher Explorer 200P

| Part | Orientation | Notes |
|---|---|---|
| Side bracket | Face plate flat on bed | Motor housing points up |
| Drive gear | Flat face on bed | Grip hub points up |
| Motor pinion | Flat face on bed | |
| Electronics box | Open top facing up | |
| Electronics lid | Flat outer face on bed | |

---

## Plate layout suggestions

You can print multiple parts together to save time. Suggested groupings for a 256×256 mm build plate:

**Plate 1 — Gears (slow settings)**
- Focuser knob gear (or drive gear)
- Motor pinion
- Use the gear preset (40 mm/s outer wall)

**Plate 2 — Structural (faster settings)**
- Clamp body / side bracket / rear cell plate
- Electronics box
- Use the structural preset (60 mm/s outer wall)

**Plate 3 — Small parts**
- Clamp lid / electronics lid
- Any spare pinions

Do not mix gears and structural parts on the same plate if using different speed profiles — Bambu Studio applies one process profile per plate (unless using multi-process mode).

---

## Post-print checks

### Gears
After printing, before installing heat-set inserts:

1. Test-mesh the large and small gear by hand
2. Mesh should be smooth — slight resistance is fine, grinding or binding is not
3. If binding: increase `gear_module` by 0.1 in the SCAD file, re-export, reprint
4. If too loose/rattly: decrease `gear_module` by 0.1

### Shaft bores
1. The focuser shaft should slip into the gear bore with light finger pressure
2. Not forced (too tight — ream gently with a round file or drill bit)
3. Not loose/wobbly (too loose — reprint with bore diameter reduced by 0.1 mm)

### Clamp / bracket
1. Test-fit on the focuser before inserting any heat-set inserts
2. The clamping slot should contact the focuser body without forcing
3. Minor tightness: lightly file the contact faces — faster than reprinting

### Heat-set inserts
1. Soldering iron at 180–200°C, pointed brass tip
2. Press slowly and perpendicular to the surface
3. Stop flush with or 0.2 mm below the surface
4. Let cool 60 seconds before applying any load

---

## Troubleshooting

| Problem | Cause | Fix |
|---|---|-----|
| Gear teeth have strings between them | Wet filament | Dry filament, reprint |
| Gear bore too tight | Printer over-extruding slightly | Calibrate e-steps or reduce bore dia by 0.1 mm in SCAD |
| First layer not sticking | Dirty PEI plate | Clean with IPA, re-level |
| PETG stringing on overhangs | Fan too low | Increase fan to 70% for overhangs only |
| Electronics box walls thin/weak | Infill too low | Use 4 walls minimum — already in preset |
| Layer delamination on bracket | Fan too high, poor bonding | Reduce fan to 40%, increase temp to 245°C |

---

## H2S-specific tips

- **AMS**: Load PETG in one slot, single-material print — no colour changes needed
- **Lidar calibration**: The H2S scans before printing; PETG on textured PEI reads reliably
- **First layer**: If first layer looks rough, wipe the plate with IPA and re-run first layer calibration
- **Plate adhesion**: If parts lift at corners (rare with PETG on textured PEI), add a 3 mm brim to structural parts only — not gears
- **AMS humidity**: Keep PETG in the AMS with desiccant. If the AMS humidity indicator turns pink, dry the filament before printing gears

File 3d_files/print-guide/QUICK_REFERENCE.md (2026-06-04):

# Print Quick Reference

One-page cheat sheet. Full details in [PRINT_GUIDE.md](PRINT_GUIDE.md).

---

## Filament: PETG — all parts, all telescopes

| Setting | Value |
|---|---|
| Nozzle | 240°C |
| Bed | 70°C |
| Plate | Textured PEI |
| Fan | 40–60% |

---

## Infill

| Part type | Infill | Pattern |
|---|---|---|
| Gears | **45%** | Gyroid |
| Everything else | 30% | Gyroid |

---

## Speed

| Part type | Outer wall | Inner wall | Infill |
|---|---|---|---|
| Gears | **40 mm/s** | 60 mm/s | 120 mm/s |
| Structural | 60 mm/s | 80 mm/s | 150 mm/s |

---

## Walls / layers — all parts

- Wall loops: **4**
- Top layers: **5**
- Bottom layers: **5**
- Supports: **None**

---

## RVO Horizon 60 ED — parts list

| # | Part | Qty | Settings | Flat face down |
|---|---|-----|---|---|
| 1 | Clamp body | 1 | Structural | Back face |
| 2 | Clamp lid | 1 | Structural | Outer face |
| 3 | Focuser knob gear | 1 | **Gears** | Non-herringbone face |
| 4 | Motor pinion | 1 | **Gears** | Flat face |
| 5 | Electronics box | 1 | Structural | Open top up |
| 6 | Electronics lid | 1 | Structural | Outer face |

---

## Celestron NexStar 8SE — parts list

| # | Part | Qty | Settings | Orientation |
|---|---|-----|---|---|
| 1 | Rear cell plate | 1 | Structural | Flat back on bed |
| 2 | Friction sleeve + gear | 1 | **Gears** | Gear face flat on bed |
| 3 | Motor pinion | 1 | **Gears** | Flat face |
| 4 | Electronics box | 1 | Structural | Open top up |
| 5 | Electronics lid | 1 | Structural | Outer face |

> ⚠ Measure `focus_shaft_od` with calipers before printing part 2. Default 13.1 mm.

---

## SkyWatcher Explorer 200P — parts list

| # | Part | Qty | Settings | Orientation |
|---|---|-----|---|---|
| 1 | Side bracket | 1 | Structural | Face plate flat on bed |
| 2 | Drive gear | 1 | **Gears** | Flat face on bed |
| 3 | Motor pinion | 1 | **Gears** | Flat face |
| 4 | Electronics box | 1 | Structural | Open top up |
| 5 | Electronics lid | 1 | Structural | Outer face |

> ⚠ Measure `focuser_body_w` with calipers before printing part 1. Default 76 mm.

---

## Print order (recommended)

1. Print gears first — quick dimensional test before committing to longer prints
2. Test shaft bore fit and gear mesh by hand
3. Print structural parts once gears are confirmed good
4. Insert heat-set inserts last, after all test-fits pass

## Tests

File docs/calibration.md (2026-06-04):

# Calibration Procedure

Run through these steps in order before using the focuser for imaging.

## Step 1 — Verify the motor turns

```bash
python3 scripts/oag_focuser_test.py --port /dev/ttyACM0 -i
focuser> move 500
focuser> pos
```

The motor should turn. If it hums but does not move, check that ULN2003 VCC is connected to the 5V pin, not 3.3V.

## Step 2 — Set zero position

Manually rotate the focuser to its physical end stop (fully inward). Then:

```bash
focuser> zero
```

The firmware stores this to flash. It persists across power cycles.

## Step 3 — Check direction

Move the focuser outward manually by rotating the focus knob, then command a move toward zero:

```bash
focuser> move 0
```

If the motor turns the focuser further outward instead of inward, reverse direction:

```bash
focuser> rev on
```

Re-zero after reversing.

## Step 4 — Measure backlash

Backlash comes from three places: the stepper motor gearbox, the 3D-printed gear mesh, and the focuser mechanism itself.

1. Move outward: `focuser> move 2000`
2. Attach a dial indicator to the focuser draw tube.
3. Move inward in 10-step increments: `focuser> move 1990`, `move 1980`, etc.
4. Note the step count at which the dial indicator first moves.
5. That count is your backlash. Set `BACKLASH_STEPS` if you add compensation logic, or note it for your imaging application.

Typical backlash with this hardware: 50–150 steps.

## Step 5 — Measure steps-per-unit (optional, for Ekos)

Ekos benefits from knowing how many focuser steps correspond to a known physical movement. Use the dial indicator:

1. Note current position.
2. Command 1000 steps: `focuser> move <current + 1000>`
3. Measure draw-tube movement in mm.
4. Enter steps-per-mm in the Ekos Focus module.

For the 28BYJ-48 in half-step mode with a 1.5-module gear train, expect roughly 4–8 steps per 0.01 mm depending on gear ratio.

## Step 6 — Test from INDI

```bash
indiserver -v indi_oag_focuser
```

Connect Ekos or PHD2, move the focuser from the UI, and confirm the draw tube moves the expected amount.

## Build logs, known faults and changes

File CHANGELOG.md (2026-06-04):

# Changelog

All notable changes will be documented here.

Format follows [Keep a Changelog](https://keepachangelog.com/en/1.0.0/).

---

## [1.0.0] — Initial release

### Added
- Arduino firmware for ESP32-S3 (Arduino Nano ESP32)
  - Half-step 28BYJ-48 drive sequence
  - Flash-based EEPROM emulation with `begin()` and `commit()`
  - Explicit `pinMode()` calls (required on ESP32-S3)
  - Motor de-energisation after every move
  - Full serial command protocol
- INDI focuser driver (C++) targeting Linux / libindi
  - Absolute and relative move
  - Abort
  - Reverse direction toggle
  - Set zero position
  - 500ms position polling while moving
- Python serial test and calibration utility
- udev rule for stable `/dev/focuser` symlink (Arduino Nano ESP32 USB CDC VID/PID)
- OpenSCAD parametric 3D mounts for:
  - RVO Horizon 60 ED (clamping bracket)
  - Celestron NexStar 8SE (rear-cell plate replacement)
  - SkyWatcher Explorer 200P (non-invasive side bracket)
- Documentation: wiring, build, calibration, 3D printing
- GitHub Actions CI: INDI driver build check on Ubuntu

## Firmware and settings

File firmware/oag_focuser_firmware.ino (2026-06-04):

/**
 * OAG Focuser Firmware — ESP32-S3 / Arduino Nano ESP32 edition
 *
 * Hardware:
 *   - Arduino Nano ESP32 (ESP32-S3R8, NORA-W106-10B module)
 *   - 28BYJ-48 stepper motor (5V, 4-phase unipolar)
 *   - ULN2003 driver board
 *
 * ── CRITICAL DIFFERENCES vs ATmega328P Nano ──────────────────────────────────
 *
 * 1. LOGIC LEVEL — The ESP32-S3 runs at 3.3 V. The ULN2003 input threshold is
 *    ~1 V, so 3.3 V logic drives it reliably. No level shifter needed.
 *
 * 2. MOTOR POWER — The 28BYJ-48 runs on 5 V. Power the ULN2003 board's VCC
 *    from the Nano ESP32's 5V pin (VBUS, available when USB is connected) or
 *    from a separate 5 V supply. Do NOT power the motor from the 3.3 V rail.
 *
 * 3. PIN DEFINITIONS — Use the Arduino D-label names (D2, D3, etc.) rather
 *    than raw integers. The Nano ESP32 has two pin-numbering modes; the D-labels
 *    work correctly in both. Using bare integers (2, 3…) maps to GPIO numbers,
 *    which are completely different from the Nano labels on this board.
 *
 * 4. pinMode() IS REQUIRED — The ESP32-S3 does NOT default output pins to LOW.
 *    Without explicit pinMode(x, OUTPUT), the ULN2003 inputs float and the
 *    motor either jitters or draws current continuously. Always call pinMode()
 *    before any digitalWrite().
 *
 * 5. EEPROM — The ESP32-S3 has no true EEPROM. The Arduino-ESP32 core emulates
 *    it using a 4 KB flash partition. You must call EEPROM.begin(size) before
 *    any read/write and EEPROM.commit() after writes, otherwise data is never
 *    actually written to flash.
 *
 * 6. STEP TIMING — The ESP32-S3 is much faster than ATmega. delayMicroseconds()
 *    is accurate but the motor needs ≥ 1 ms per step at full speed to avoid
 *    missing steps. 1200 µs half-step delay is conservative and reliable.
 *
 * ── Wiring ────────────────────────────────────────────────────────────────────
 *   ULN2003 board → Nano ESP32 pin
 *   IN1            → D2
 *   IN2            → D3
 *   IN3            → D4
 *   IN4            → D5
 *   VCC            → 5V  (VBUS — USB power or external 5 V)
 *   GND            → GND
 *
 *   Pins D2-D5 were chosen because:
 *     - They are not strapping pins (avoids boot issues)
 *     - They are not the UART pins (D0/D1)
 *     - Confirmed working with ULN2003 in community testing
 *
 * ── Serial protocol ───────────────────────────────────────────────────────────
 *   115200 baud, newline-terminated. Identical to the jlecomte ASCOM driver
 *   protocol so the INDI driver works without modification.
 */

#include <EEPROM.h>

// ── Motor pins — use D-label names, not raw GPIO integers ─────────────────────
#define IN1 D2
#define IN2 D3
#define IN3 D4
#define IN4 D5

// ── Half-step sequence for 28BYJ-48 ──────────────────────────────────────────
// 8-phase half-step. Gives smoother motion and double the resolution vs full-step.
const uint8_t STEP_SEQ[8][4] = {
  {1, 0, 0, 0},
  {1, 1, 0, 0},
  {0, 1, 0, 0},
  {0, 1, 1, 0},
  {0, 0, 1, 0},
  {0, 0, 1, 1},
  {0, 0, 0, 1},
  {1, 0, 0, 1}
};

// ── EEPROM layout ─────────────────────────────────────────────────────────────
// ESP32-S3: must call EEPROM.begin() before use, EEPROM.commit() after write.
#define EEPROM_SIZE      8
#define EEPROM_MAGIC_0   0x00
#define EEPROM_MAGIC_1   0x01
#define EEPROM_POS_ADDR  0x02   // 4 bytes (long)
#define EEPROM_REV_ADDR  0x06   // 1 byte
#define MAGIC_BYTE_0     0xDA
#define MAGIC_BYTE_1     0x7A

// ── Limits ────────────────────────────────────────────────────────────────────
#define MAX_POSITION     32767L
#define STEP_DELAY_US    1200   // µs per half-step — do not reduce below ~800

// ── State ─────────────────────────────────────────────────────────────────────
long    currentPosition  = 0;
long    targetPosition   = 0;
bool    isMoving         = false;
bool    reverseDirection = false;
uint8_t stepIndex        = 0;
String  inputBuffer      = "";

// ── EEPROM helpers (ESP32-S3 flash emulation) ─────────────────────────────────
void saveState() {
  EEPROM.write(EEPROM_MAGIC_0, MAGIC_BYTE_0);
  EEPROM.write(EEPROM_MAGIC_1, MAGIC_BYTE_1);

  // Write long position byte-by-byte
  uint8_t *p = (uint8_t *)&currentPosition;
  for (int i = 0; i < 4; i++) {
    EEPROM.write(EEPROM_POS_ADDR + i, p[i]);
  }

  EEPROM.write(EEPROM_REV_ADDR, reverseDirection ? 0x01 : 0x00);
  EEPROM.commit();  // ← required on ESP32; no-op on AVR
}

void loadState() {
  if (EEPROM.read(EEPROM_MAGIC_0) == MAGIC_BYTE_0 &&
      EEPROM.read(EEPROM_MAGIC_1) == MAGIC_BYTE_1) {
    uint8_t *p = (uint8_t *)&currentPosition;
    for (int i = 0; i < 4; i++) {
      p[i] = EEPROM.read(EEPROM_POS_ADDR + i);
    }
    reverseDirection = (EEPROM.read(EEPROM_REV_ADDR) == 0x01);
  } else {
    currentPosition  = 0;
    reverseDirection = false;
    saveState();
  }
  targetPosition = currentPosition;
}

// ── Motor helpers ─────────────────────────────────────────────────────────────
void applyStep(uint8_t idx) {
  digitalWrite(IN1, STEP_SEQ[idx][0]);
  digitalWrite(IN2, STEP_SEQ[idx][1]);
  digitalWrite(IN3, STEP_SEQ[idx][2]);
  digitalWrite(IN4, STEP_SEQ[idx][3]);
}

void deenergise() {
  // De-energise fully — prevents heat buildup and vibration when idle.
  // Especially important on the ESP32-S3: pins stay in their last state
  // indefinitely unlike AVR which can be reset.
  digitalWrite(IN1, LOW);
  digitalWrite(IN2, LOW);
  digitalWrite(IN3, LOW);
  digitalWrite(IN4, LOW);
}

void stepOnce(bool forward) {
  bool actualForward = reverseDirection ? !forward : forward;
  if (actualForward) {
    stepIndex = (stepIndex + 1) % 8;
  } else {
    stepIndex = (stepIndex + 7) % 8;
  }
  applyStep(stepIndex);
  delayMicroseconds(STEP_DELAY_US);
}

// ── Command handler ───────────────────────────────────────────────────────────
void handleCommand(String cmd) {
  cmd.trim();

  if (cmd == "COMMAND:FOCUSER:GETPOSITION") {
    Serial.println("REPLY:FOCUSER:POSITION:" + String(currentPosition));

  } else if (cmd == "COMMAND:FOCUSER:ISMOVING") {
    Serial.println("REPLY:FOCUSER:ISMOVING:" + String(isMoving ? "1" : "0"));

  } else if (cmd == "COMMAND:FOCUSER:GETMAXPOSITION") {
    Serial.println("REPLY:FOCUSER:MAXPOSITION:" + String(MAX_POSITION));

  } else if (cmd == "COMMAND:FOCUSER:SETZERO") {
    currentPosition = 0;
    targetPosition  = 0;
    saveState();
    Serial.println("REPLY:FOCUSER:OK");

  } else if (cmd == "COMMAND:FOCUSER:HALT") {
    targetPosition = currentPosition;
    isMoving       = false;
    deenergise();
    saveState();
    Serial.println("REPLY:FOCUSER:OK");

  } else if (cmd.startsWith("COMMAND:FOCUSER:MOVE:")) {
    long requested = cmd.substring(21).toInt();
    requested = constrain(requested, 0L, MAX_POSITION);
    targetPosition = requested;
    isMoving = (targetPosition != currentPosition);
    Serial.println("REPLY:FOCUSER:OK");

  } else if (cmd == "COMMAND:FOCUSER:GETREVERSE") {
    Serial.println("REPLY:FOCUSER:REVERSE:" + String(reverseDirection ? "1" : "0"));

  } else if (cmd.startsWith("COMMAND:FOCUSER:SETREVERSE:")) {
    reverseDirection = (cmd.substring(27) == "1");
    saveState();
    Serial.println("REPLY:FOCUSER:OK");

  } else if (cmd == "COMMAND:FOCUSER:HANDSHAKE") {
    Serial.println("REPLY:FOCUSER:READY");

  } else {
    Serial.println("REPLY:FOCUSER:ERROR:UNKNOWN_COMMAND");
  }
}

// ── Setup ─────────────────────────────────────────────────────────────────────
void setup() {
  // pinMode MUST be called before digitalWrite on ESP32-S3.
  // Skipping this causes the motor pins to float and the ULN2003 to behave
  // erratically — the most common cause of "works on Nano, fails on ESP32".
  pinMode(IN1, OUTPUT);
  pinMode(IN2, OUTPUT);
  pinMode(IN3, OUTPUT);
  pinMode(IN4, OUTPUT);
  deenergise();

  // Initialise flash-based EEPROM emulation (ESP32 requirement)
  EEPROM.begin(EEPROM_SIZE);

  Serial.begin(115200);
  loadState();

  // Signal ready to INDI driver / test utility
  Serial.println("REPLY:FOCUSER:READY");
}

// ── Loop ──────────────────────────────────────────────────────────────────────
void loop() {
  // ── Serial input ──────────────────────────────────────────────────────────
  while (Serial.available() > 0) {
    char c = (char)Serial.read();
    if (c == '\n' || c == '\r') {
      if (inputBuffer.length() > 0) {
        handleCommand(inputBuffer);
        inputBuffer = "";
      }
    } else {
      inputBuffer += c;
    }
  }

  // ── Stepping ──────────────────────────────────────────────────────────────
  if (isMoving) {
    bool forward = (targetPosition > currentPosition);
    stepOnce(forward);

    currentPosition += forward ? 1 : -1;

    if (currentPosition == targetPosition) {
      isMoving = false;
      deenergise();
      saveState();
    }
  }
}

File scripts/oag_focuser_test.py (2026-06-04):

#!/usr/bin/env python3
"""
oag_focuser_test.py
-------------------
Standalone serial tester for the OAG focuser firmware.
Lets you talk to the Arduino directly without INDI — useful for initial
calibration, verifying the firmware, and measuring backlash.

Usage:
    python3 oag_focuser_test.py --port /dev/ttyUSB0

Alternatively, run with --interactive for a simple command prompt.

Requires: pyserial  (pip install pyserial)
"""

import argparse
import sys
import time
import serial

BAUD      = 115200
TIMEOUT   = 2.0   # seconds


def open_port(port: str) -> serial.Serial:
    s = serial.Serial(
        port=port,
        baudrate=BAUD,
        timeout=TIMEOUT,
        bytesize=serial.EIGHTBITS,
        parity=serial.PARITY_NONE,
        stopbits=serial.STOPBITS_ONE,
    )
    # Arduino resets when DTR is toggled; wait for it to boot
    time.sleep(2.0)
    s.reset_input_buffer()
    return s


def send(ser: serial.Serial, cmd: str) -> str:
    """Send a command and return the stripped reply."""
    full = cmd.strip() + "\n"
    ser.write(full.encode())
    reply = ser.readline().decode(errors="replace").strip()
    return reply


def handshake(ser: serial.Serial) -> bool:
    reply = send(ser, "COMMAND:FOCUSER:HANDSHAKE")
    return "READY" in reply


def get_position(ser: serial.Serial) -> int:
    reply = send(ser, "COMMAND:FOCUSER:GETPOSITION")
    # REPLY:FOCUSER:POSITION:12345
    try:
        return int(reply.split(":")[-1])
    except ValueError:
        return -1


def is_moving(ser: serial.Serial) -> bool:
    reply = send(ser, "COMMAND:FOCUSER:ISMOVING")
    return ":1" in reply


def move_to(ser: serial.Serial, position: int) -> bool:
    reply = send(ser, f"COMMAND:FOCUSER:MOVE:{position}")
    return "OK" in reply


def halt(ser: serial.Serial) -> bool:
    reply = send(ser, "COMMAND:FOCUSER:HALT")
    return "OK" in reply


def set_zero(ser: serial.Serial) -> bool:
    reply = send(ser, "COMMAND:FOCUSER:SETZERO")
    return "OK" in reply


def set_reverse(ser: serial.Serial, enabled: bool) -> bool:
    reply = send(ser, f"COMMAND:FOCUSER:SETREVERSE:{'1' if enabled else '0'}")
    return "OK" in reply


def wait_for_stop(ser: serial.Serial, poll_interval: float = 0.25):
    """Block until the focuser reports it has stopped moving."""
    while is_moving(ser):
        pos = get_position(ser)
        print(f"  Moving... position = {pos}", end="\r", flush=True)
        time.sleep(poll_interval)
    print()


def run_self_test(ser: serial.Serial):
    """Basic self-test: handshake, read position, small move, halt."""
    print("── Self-test ────────────────────────────────────────")

    if not handshake(ser):
        print("FAIL: Handshake — check firmware and port.")
        return

    print("PASS: Handshake")

    pos = get_position(ser)
    print(f"INFO: Current position = {pos}")

    target = pos + 200
    print(f"INFO: Moving to {target} ...")
    if not move_to(ser, target):
        print("FAIL: Move command rejected.")
        return

    wait_for_stop(ser)
    new_pos = get_position(ser)
    print(f"INFO: Position after move = {new_pos}")

    if abs(new_pos - target) <= 2:
        print("PASS: Move accuracy OK")
    else:
        print(f"WARN: Expected ~{target}, got {new_pos}")

    print("INFO: Returning to original position ...")
    move_to(ser, pos)
    wait_for_stop(ser)
    print(f"INFO: Final position = {get_position(ser)}")
    print("── Self-test complete ───────────────────────────────")


def interactive(ser: serial.Serial):
    """Simple REPL for manual testing."""
    print("OAG Focuser interactive mode. Type 'help' for commands, 'quit' to exit.")
    commands = {
        "pos":      lambda _: print(f"Position: {get_position(ser)}"),
        "moving":   lambda _: print(f"Moving: {is_moving(ser)}"),
        "halt":     lambda _: print("OK" if halt(ser) else "FAIL"),
        "zero":     lambda _: print("OK" if set_zero(ser) else "FAIL"),
        "rev on":   lambda _: print("OK" if set_reverse(ser, True) else "FAIL"),
        "rev off":  lambda _: print("OK" if set_reverse(ser, False) else "FAIL"),
        "test":     lambda _: run_self_test(ser),
        "help": lambda _: print(
            "Commands: pos | moving | halt | zero | rev on | rev off | "
            "move <n> | raw <CMD> | test | quit"
        ),
    }

    while True:
        try:
            line = input("focuser> ").strip()
        except (EOFError, KeyboardInterrupt):
            break

        if line in ("quit", "exit", "q"):
            break
        elif line.startswith("move "):
            try:
                n = int(line.split()[1])
                print("OK" if move_to(ser, n) else "FAIL")
                wait_for_stop(ser)
                print(f"Position: {get_position(ser)}")
            except (IndexError, ValueError):
                print("Usage: move <position>")
        elif line.startswith("raw "):
            cmd = line[4:]
            print(send(ser, cmd))
        elif line in commands:
            commands[line](None)
        else:
            print("Unknown command. Type 'help'.")


def main():
    parser = argparse.ArgumentParser(description="OAG Focuser serial tester")
    parser.add_argument("--port", default="/dev/ttyUSB0",
                        help="Serial port (default: /dev/ttyUSB0)")
    parser.add_argument("--test", action="store_true",
                        help="Run automated self-test and exit")
    parser.add_argument("--interactive", "-i", action="store_true",
                        help="Enter interactive prompt")
    args = parser.parse_args()

    print(f"Opening {args.port} at {BAUD} baud ...")
    try:
        ser = open_port(args.port)
    except serial.SerialException as e:
        print(f"Error: {e}", file=sys.stderr)
        sys.exit(1)

    if args.test:
        run_self_test(ser)
    elif args.interactive:
        interactive(ser)
    else:
        # Default: print status
        if handshake(ser):
            pos     = get_position(ser)
            moving  = is_moving(ser)
            rev_raw = send(ser, "COMMAND:FOCUSER:GETREVERSE")
            rev     = ":1" in rev_raw
            print(f"Position : {pos}")
            print(f"Moving   : {moving}")
            print(f"Reversed : {rev}")
        else:
            print("Handshake failed.", file=sys.stderr)
            sys.exit(1)

    ser.close()


if __name__ == "__main__":
    main()

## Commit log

2026-06-04 Initial release v1.0.0
    [nexstar_8se_motor_mount.scad, rvo_horizon_60ed_motor_mount.scad, sw_explorer_200p_motor_mount.scad]
2026-06-04 Add mount diagrams and unblock docs/images from gitignore
2026-06-04 Add print guides
2026-06-04 Add STL print files
    [nexstar_8se_motor_mount.stl, rvo_horizon_60ed_motor_mount.stl, sw_explorer_200p_motor_mount.stl]
2026-06-27 Add CC BY-NC-SA 4.0 licence — non-commercial use only
    Copyright (c) 2026 Neil Manfred
    Commercial licensing: neilmanfredit@gmail.com
    https://creativecommons.org/licenses/by-nc-sa/4.0/
